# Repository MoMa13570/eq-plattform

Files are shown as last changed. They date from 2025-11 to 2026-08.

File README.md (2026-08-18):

# EQ Plattform

Eine DIY-Nachführplattform für Dobson-Teleskope mit Arduino Uno, Nano oder
ESP32, NEMA17-Schrittmotor und TMC2209-Treiber. Die ESP32-Firmware bringt
zusätzlich einen eigenen WLAN-Hotspot und eine responsive Websteuerung mit.

## Direkt starten

- [Projekt-Website und Bauübersicht](https://moma13570.github.io/eq-plattform/)
- [Firmware im Browser installieren](https://moma13570.github.io/eq-plattform/flasher/)
- [Aktuelle Firmware herunterladen](https://github.com/MoMa13570/eq-plattform/releases/latest)
- [Fertige Firmware im Repository](release/)
- [Bauanleitung als PDF](build_instructions/buildinstruction_EQ_Plattform.pdf)
- [Stückliste als CSV](part%20list/Teileliste_DM%20EQ%20Plattform.csv)

Der Browser-Flasher benötigt Chrome oder Edge auf einem Desktop-Rechner. Die
HEX-Datei wird lokal verarbeitet und nicht an einen Server übertragen.

## Inhalt

- `hardware/mechanical/` – STEP-Dateien für Standard- und Simple-Mechanik
- `hardware/circuitboard/` – Schaltplan, PCB-Daten und Elektronikgehäuse
- `software/EQ-Plattform_TMC2209/` – PlatformIO-Projekt und Firmware-Quellcode
- `part list/` – Stückliste
- `build_instructions/` – ausführliche Bauanleitung
- `flasher/` – statischer Web-Serial-Flasher

## Firmware selbst kompilieren

Das PlatformIO-Projekt unterstützt Arduino Uno, Nano und ESP32:

```text
software/EQ-Plattform_TMC2209/
```

Die wichtigsten Umgebungen in `platformio.ini` sind `uno`, `nano` und `esp32`.
Details zur ESP32-Pinbelegung und Web-App stehen in der
[Software-Dokumentation](software/README.md). Für Uno/Nano ist der fertige
HEX-Download im aktuellen GitHub Release einfacher.

## Lizenz

Siehe [LICENSE.rtf](LICENSE.rtf).

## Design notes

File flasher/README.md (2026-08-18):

# EQ Firmware Flasher

Statische Chrome-Web-App zum Übertragen einer Intel-HEX-Firmware auf:

- Arduino Uno
- Arduino Nano
- Arduino Nano (alter Bootloader)
- ESP32 DevKit V1

Die App verwendet die Web Serial API direkt im Browser. Es gibt kein Backend,
kein Benutzerkonto und keinen Upload der Firmware an einen Server.

Für Uno/Nano verarbeitet der Flasher Intel-HEX und spricht das STK500v1-
Bootloaderprotokoll. Für den ESP32 wird ein zusammengeführtes Factory-BIN ab
Adresse `0x0` mit Espressifs `esptool-js` übertragen. Die passenden fertigen
Dateien liegen im Verzeichnis [`release/`](../release/).

`esptool-js` 0.5.7 ist lokal unter `vendor/` eingebunden, sodass der Flasher
zur Laufzeit keine Bibliothek von einem externen CDN nachladen muss. Die
Apache-2.0-Lizenz liegt daneben.

Nach der Veröffentlichung über GitHub Pages:

<https://moma13570.github.io/eq-plattform/flasher/>

Voraussetzungen: Chrome oder Edge auf einem Desktop-Rechner sowie eine
HTTPS-Verbindung (bei GitHub Pages automatisch gegeben).

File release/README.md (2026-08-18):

# Fertige Firmware

- `EQ-Plattform-UNO-NANO.hex` – Arduino Uno oder Nano mit ATmega328P
- `EQ-Plattform-ESP32.factory.bin` – vollständiges ESP32 DevKit V1 Image

Beide Dateien können direkt im [Web-Flasher](../flasher/index.html) verwendet
werden. Das ESP32-Factory-Image enthält Bootloader, Partitionstabelle und
Anwendung und wird ab Flash-Adresse `0x0` installiert.

Bei einem Git-Tag wie `v1.0.0` baut der Workflow `firmware-release.yml` beide
Dateien erneut und hängt sie zusammen mit `SHA256SUMS.txt` an den GitHub
Release. Er kann außerdem manuell als Workflow gestartet werden.

## SHA-256

```text
a018c9d37cf94f3ed3204fbee39d7b598d2756b0838089d841da10bda20a1d82  EQ-Plattform-UNO-NANO.hex
f4a5176cb3ebf21efc48b64490342c9812eb65955f2bdc9ecd68fb28551eea28  EQ-Plattform-ESP32.factory.bin
```

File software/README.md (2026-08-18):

# Firmware

## Einfach installieren

1. Die aktuelle HEX-Datei im
   [GitHub Release](https://github.com/MoMa13570/eq-plattform/releases/latest)
   herunterladen.
2. Den
   [EQ Firmware Flasher](https://moma13570.github.io/eq-plattform/flasher/)
   in Chrome oder Edge öffnen.
3. Board und HEX-Datei auswählen, Arduino verbinden und installieren.

Für den ESP32 im Flasher `ESP32 DevKit` wählen und die mitgelieferte
`EQ-Plattform-ESP32.factory.bin` verwenden. Der Flasher kann sie direkt laden;
ein vorheriger Download ist nicht nötig.

Die veröffentlichte Firmware ist für ATmega328P-Boards ausgelegt. Dasselbe
Firmware-Abbild funktioniert auf Arduino Uno und Nano; im Flasher wird das
Board ausgewählt, damit das passende Bootloader-Protokoll verwendet wird.

## ESP32 mit Web-App

Zusätzlich gibt es die PlatformIO-Umgebung `esp32` für ein ESP32 DevKit V1.
Sie enthält dieselbe Steuerung einschließlich OLED, Endschaltern, Tracking,
Mondrate und Homing. Der ESP32 öffnet außerdem den Hotspot `EQ-Plattform`
(Passwort `eqplattform`). Nach dem Verbinden ist die Steuerung unter
`http://192.168.4.1` erreichbar. Auf vielen Smartphones öffnet sich die
Web-App durch die integrierte Captive-Portal-Erkennung automatisch.

Die Web-App zeigt den Live-Status und bietet:

- Tracking starten/stoppen, Richtung Nord/Süd und Mondrate
- Homing und Sofort-Stopp
- konfigurierbaren Poti-Bereich oder Betrieb ohne Poti
- getrennte TMC2209-Ströme für Tracking, schnelles und langsames Homing
- einstellbare Homing-Geschwindigkeiten

Alle Einstellungen werden im Flash des ESP32 gespeichert.

### Pinbelegung ESP32 DevKit V1

| Funktion | GPIO |
| --- | ---: |
| STEP / DIR / EN | 25 / 26 / 27 |
| Poti | 34 |
| Richtung Nord / Süd | 32 / 33 |
| Home-Taster | 13 |
| Endschalter Home / Ende | 18 / 19 |
| TMC2209 UART RX / TX | 16 / 17 |
| OLED SDA / SCL | 21 / 22 |

Taster, Richtungsschalter und Endschalter schalten gegen GND. Der ESP32 ist
nicht 5-V-tolerant; alle Signale müssen mit 3,3 V kompatibel sein. Die Masse
von ESP32, TMC2209 und Motorversorgung muss verbunden werden.

Beim üblichen BTT TMC2209 V1.3 werden GPIO 16 (RX) direkt und GPIO 17 (TX)
über einen 1-kΩ-Widerstand gemeinsam an `PDN_UART` angeschlossen. Die
eingestellten RMS-Ströme sind Sicherheitsgrenzen der Software, ersetzen aber
nicht die Prüfung, ob Motor, Treiber und Kühlung dafür ausgelegt sind.

Kompilieren und hochladen:

```bash
cd software/EQ-Plattform_TMC2209
pio run -e esp32
pio run -e esp32 -t upload
```

Fertige Images für den Web-Flasher liegen unter [`release/`](../release/).
Für den ESP32 muss dort die Datei mit der Endung `.factory.bin` verwendet
werden; die normale PlatformIO-Datei `firmware.bin` enthält nur die Anwendung.

## Quellcode

Das PlatformIO-Projekt befindet sich in
[`EQ-Plattform_TMC2209/`](EQ-Plattform_TMC2209/). Die Umgebungen `uno`, `nano`
und `esp32` bauen die jeweilige Firmware mit Endstop- und Homing-Unterstützung.

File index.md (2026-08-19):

---
title: EQ Plattform
description: DIY-Nachführplattform für Dobson-Teleskope mit Arduino, NEMA17 und TMC2209
lang: de
---

<style>
  :root {
    --eq-bg: #f2f6f5;
    --eq-surface: #ffffff;
    --eq-surface-soft: #e9f0ef;
    --eq-ink: #13272b;
    --eq-muted: #5d7074;
    --eq-line: #d4e0de;
    --eq-accent: #087e84;
    --eq-accent-dark: #075a60;
    --eq-warm: #e99b38;
    --eq-red: #c8322b;
    --eq-night: #0b2d32;
    --eq-radius: 1.25rem;
    --eq-shadow: 0 24px 60px rgba(11, 45, 50, 0.1);
  }

  html {
    scroll-behavior: smooth;
  }

  body {
    margin: 0;
    background: var(--eq-bg);
  }

  .container-lg {
    max-width: none !important;
    margin: 0 !important;
    padding: 0 !important;
  }

  .container-lg > h1:first-child {
    display: none;
  }

  .markdown-body {
    color: var(--eq-ink);
    font-family: Inter, ui-sans-serif, -apple-system, BlinkMacSystemFont, "Segoe UI", sans-serif;
    font-size: 16px;
    line-height: 1.65;
  }

  .markdown-body h1,
  .markdown-body h2,
  .markdown-body h3,
  .markdown-body p,
  .markdown-body figure,
  .markdown-body ul {
    margin-top: 0;
  }

  .markdown-body a {
    color: var(--eq-accent-dark);
  }

  .eq-page {
    min-height: 100vh;
    overflow: hidden;
  }

  .eq-wrap {
    width: min(1120px, calc(100% - 40px));
    margin: 0 auto;
  }

  .eq-nav {
    position: relative;
    z-index: 10;
    display: flex;
    min-height: 76px;
    align-items: center;
    justify-content: space-between;
    gap: 2rem;
  }

  .eq-brand {
    display: inline-flex;
    align-items: center;
    gap: 0.75rem;
    color: var(--eq-ink) !important;
    font-weight: 800;
    letter-spacing: -0.025em;
    text-decoration: none !important;
  }

  .eq-brand-mark {
    display: grid;
    width: 2.25rem;
    height: 2.25rem;
    place-items: center;
    border-radius: 0.7rem;
    background: var(--eq-night);
    color: #ffffff;
    font-size: 0.78rem;
    letter-spacing: -0.04em;
  }

  .eq-nav-links {
    display: flex;
    align-items: center;
    gap: 1.3rem;
  }

  .eq-nav-links a {
    color: var(--eq-muted) !important;
    font-size: 0.9rem;
    font-weight: 650;
    text-decoration: none !important;
  }

  .eq-nav-links a:hover {
    color: var(--eq-accent-dark) !important;
  }

  .eq-hero {
    display: grid;
    grid-template-columns: minmax(0, 1fr) minmax(360px, 0.86fr);
    gap: clamp(2rem, 5vw, 5rem);
    align-items: center;
    padding: clamp(3rem, 7vw, 6rem) 0 clamp(4rem, 8vw, 7rem);
  }

  .eq-kicker {
    margin-bottom: 1rem !important;
    color: var(--eq-accent-dark);
    font: 750 0.78rem ui-monospace, SFMono-Regular, Menlo, monospace;
    letter-spacing: 0.13em;
    text-transform: uppercase;
  }

  .eq-hero h1 {
    max-width: 12ch;
    margin-bottom: 1.4rem;
    color: var(--eq-night);
    font-size: clamp(3.3rem, 8vw, 6.5rem);
    font-weight: 720;
    letter-spacing: -0.072em;
    line-height: 0.9;
  }

  .eq-lead {
    max-width: 42rem;
    margin-bottom: 1.6rem !important;
    color: var(--eq-muted);
    font-size: clamp(1.05rem, 2vw, 1.25rem);
    line-height: 1.6;
  }

  .eq-actions {
    display: flex;
    flex-wrap: wrap;
    gap: 0.75rem;
  }

  .eq-button {
    display: inline-flex;
    min-height: 3rem;
    align-items: center;
    justify-content: center;
    padding: 0.7rem 1.1rem;
    border: 1px solid var(--eq-accent);
    border-radius: 0.75rem;
    background: var(--eq-accent);
    color: #ffffff !important;
    font-size: 0.94rem;
    font-weight: 750;
    text-decoration: none !important;
    transition: transform 160ms ease, box-shadow 160ms ease;
  }

  .eq-button:hover {
    transform: translateY(-2px);
    box-shadow: 0 12px 24px rgba(8, 126, 132, 0.18);
  }

  .eq-button.secondary {
    border-color: var(--eq-line);
    background: var(--eq-surface);
    color: var(--eq-ink) !important;
  }

  .eq-facts {
    display: flex;
    flex-wrap: wrap;
    gap: 0.55rem;
    margin-top: 1.6rem;
  }

  .eq-fact {
    padding: 0.35rem 0.65rem;
    border: 1px solid var(--eq-line);
    border-radius: 999px;
    background: rgba(255, 255, 255, 0.55);
    color: var(--eq-muted);
    font-size: 0.78rem;
    font-weight: 650;
  }

  .eq-hero-media {
    position: relative;
    margin: 0;
  }

  .eq-hero-media::before {
    position: absolute;
    inset: -10% -12% auto auto;
    width: 75%;
    aspect-ratio: 1;
    border-radius: 50%;
    background: rgba(8, 126, 132, 0.12);
    content: "";
    filter: blur(1px);
  }

  .eq-hero-media img {
    position: relative;
    width: 100%;
    aspect-ratio: 1.05;
    border: 1px solid rgba(255, 255, 255, 0.8);
    border-radius: 2rem;
    object-fit: cover;
    box-shadow: var(--eq-shadow);
  }

  .eq-hero-media figcaption {
    position: absolute;
    right: 1rem;
    bottom: 1rem;
    max-width: 14rem;
    padding: 0.55rem 0.75rem;
    border: 1px solid rgba(255, 255, 255, 0.35);
    border-radius: 0.65rem;
    background: rgba(11, 45, 50, 0.84);
    color: #ffffff;
    font-size: 0.75rem;
    backdrop-filter: blur(8px);
  }

  .eq-intro {
    display: grid;
    grid-template-columns: minmax(220px, 0.3fr) minmax(0, 0.7fr);
    gap: clamp(1.5rem, 5vw, 4rem);
    align-items: start;
    margin-bottom: 0;
    padding: clamp(1.5rem, 4vw, 2.5rem);
    border: 1px solid var(--eq-line);
    border-radius: var(--eq-radius);
    background: var(--eq-surface);
    box-shadow: 0 18px 45px rgba(11, 45, 50, 0.07);
  }

  .eq-intro h2 {
    margin-bottom: 0;
    color: var(--eq-night);
    font-size: clamp(1.8rem, 4vw, 2.7rem);
    font-weight: 720;
    letter-spacing: -0.05em;
    line-height: 1;
  }

  .eq-intro p {
    margin-bottom: 0;
    color: var(--eq-muted);
    font-size: 1.04rem;
    line-height: 1.75;
  }

  .eq-video {
    display: grid;
    grid-template-columns: minmax(240px, 0.38fr) minmax(0, 0.62fr);
    gap: clamp(2rem, 6vw, 5rem);
    align-items: center;
  }

  .eq-video-copy h2 {
    margin-bottom: 1.1rem;
    color: var(--eq-night);
    font-size: clamp(2.1rem, 5vw, 3.8rem);
    font-weight: 720;
    letter-spacing: -0.055em;
    line-height: 1;
  }

  .eq-video-copy > p:last-child {
    margin-bottom: 0;
    color: var(--eq-muted);
    font-size: 1.05rem;
  }

  .eq-video-placeholder {
    position: relative;
    display: grid;
    aspect-ratio: 16 / 9;
    overflow: hidden;
    place-items: center;
    border: 1px solid rgba(255, 255, 255, 0.14);
    border-radius: var(--eq-radius);
    background:
      radial-gradient(circle at 50% 35%, rgba(8, 126, 132, 0.42), transparent 46%),
      var(--eq-night);
    box-shadow: var(--eq-shadow);
    color: #ffffff;
  }

  .eq-video-placeholder::before {
    position: absolute;
    inset: 1rem;
    border: 1px solid rgba(255, 255, 255, 0.08);
    border-radius: calc(var(--eq-radius) - 0.4rem);
    content: "";
  }

  .eq-video-placeholder-content {
    position: relative;
    z-index: 1;
    display: grid;
    justify-items: center;
    padding: 2rem;
    text-align: center;
  }

  .eq-video-play-icon {
    position: relative;
    width: 4rem;
    height: 4rem;
    margin-bottom: 1rem;
    border: 1px solid rgba(255, 255, 255, 0.3);
    border-radius: 50%;
    background: rgba(255, 255, 255, 0.12);
    backdrop-filter: blur(8px);
  }

  .eq-video-play-icon::after {
    position: absolute;
    top: 50%;
    left: 53%;
    border-top: 0.55rem solid transparent;
    border-bottom: 0.55rem solid transparent;
    border-left: 0.85rem solid #ffffff;
    content: "";
    transform: translate(-50%, -50%);
  }

  .eq-video-placeholder strong {
    color: #ffffff;
    font-size: 1.1rem;
  }

  .eq-video-placeholder small {
    margin-top: 0.25rem;
    color: #b7c8c8;
  }

  .eq-section {
    padding: clamp(4rem, 8vw, 7rem) 0;
  }

  .eq-section.soft {
    position: relative;
  }

  .eq-section.soft::before {
    position: absolute;
    z-index: -1;
    top: 0;
    right: 50%;
    bottom: 0;
    left: 50%;
    width: 100vw;
    margin-right: -50vw;
    margin-left: -50vw;
    background: var(--eq-surface-soft);
    content: "";
  }

  .eq-section.dark {
    position: relative;
    color: #ffffff;
  }

  .eq-section.dark::before {
    position: absolute;
    z-index: -1;
    top: 0;
    right: 50%;
    bottom: 0;
    left: 50%;
    width: 100vw;
    margin-right: -50vw;
    margin-left: -50vw;
    background: var(--eq-night);
    content: "";
  }

  .eq-section-heading {
    display: grid;
    grid-template-columns: minmax(0, 0.62fr) minmax(280px, 0.38fr);
    gap: 3rem;
    align-items: end;
    margin-bottom: 2.2rem;
  }

  .eq-section-heading h2,
  .eq-split-copy h2 {
    margin-bottom: 0;
    color: inherit;
    font-size: clamp(2.1rem, 5vw, 3.8rem);
    font-weight: 720;
    letter-spacing: -0.055em;
    line-height: 1;
  }

  .eq-section-heading p {
    margin-bottom: 0;
    color: var(--eq-muted);
  }

  .eq-section.dark .eq-section-heading p,
  .eq-section.dark .eq-muted {
    color: #b7c8c8;
  }

  .eq-split {
    display: grid;
    grid-template-columns: minmax(0, 0.9fr) minmax(360px, 1.1fr);
    gap: clamp(2rem, 6vw, 5rem);
    align-items: center;
  }

  .eq-split.reverse {
    grid-template-columns: minmax(360px, 1.1fr) minmax(0, 0.9fr);
  }

  .eq-split-copy > p {
    color: var(--eq-muted);
    font-size: 1.05rem;
  }

  .eq-split-copy h2 {
    margin-bottom: 1.2rem;
  }

  .eq-diagram,
  .eq-photo-card {
    margin: 0;
    overflow: hidden;
    border: 1px solid var(--eq-line);
    border-radius: var(--eq-radius);
    background: var(--eq-surface);
    box-shadow: var(--eq-shadow);
  }

  .eq-diagram {
    padding: 1.25rem;
  }

  .eq-diagram img,
  .eq-photo-card img {
    display: block;
    width: 100%;
    margin: 0;
  }

  .eq-diagram figcaption,
  .eq-photo-card figcaption {
    padding: 0.8rem 1rem 0.95rem;
    color: var(--eq-muted);
    font-size: 0.8rem;
  }

  .eq-checks {
    display: grid;
    gap: 0.8rem;
    margin: 1.5rem 0 0;
    padding: 0;
    list-style: none;
  }

  .eq-checks li {
    position: relative;
    padding-left: 1.7rem;
    color: var(--eq-ink);
  }

  .eq-checks li::before {
    position: absolute;
    top: 0.42rem;
    left: 0;
    width: 0.7rem;
    height: 0.7rem;
    border: 2px solid var(--eq-accent);
    border-radius: 50%;
    content: "";
  }

  .eq-card-grid {
    display: grid;
    grid-template-columns: repeat(3, minmax(0, 1fr));
    gap: 1rem;
  }

  .eq-card {
    padding: 1.35rem;
    border: 1px solid var(--eq-line);
    border-radius: 1rem;
    background: var(--eq-surface);
  }

  .eq-card-label {
    display: inline-block;
    margin-bottom: 1rem;
    color: var(--eq-accent-dark);
    font: 700 0.72rem ui-monospace, SFMono-Regular, Menlo, monospace;
    letter-spacing: 0.1em;
    text-transform: uppercase;
  }

  .eq-card h3 {
    margin-bottom: 0.55rem;
    color: var(--eq-ink);
    font-size: 1.15rem;
  }

  .eq-card p,
  .eq-card li {
    color: var(--eq-muted);
    font-size: 0.93rem;
  }

  .eq-card ul {
    margin-bottom: 0;
    padding-left: 1.1rem;
  }

  .eq-step-grid {
    display: grid;
    grid-template-columns: repeat(3, minmax(0, 1fr));
    gap: 1rem;
  }

  .eq-step {
    min-height: 12rem;
    padding: 1.3rem;
    border: 1px solid var(--eq-line);
    border-radius: 1rem;
    background: rgba(255, 255, 255, 0.72);
  }

  .eq-step-number {
    display: grid;
    width: 2.15rem;
    height: 2.15rem;
    margin-bottom: 1.8rem;
    place-items: center;
    border-radius: 0.65rem;
    background: var(--eq-night);
    color: #ffffff;
    font: 700 0.78rem ui-monospace, SFMono-Regular, Menlo, monospace;
  }

  .eq-step h3 {
    margin-bottom: 0.45rem;
    color: var(--eq-ink);
    font-size: 1.05rem;
  }

  .eq-step p {
    margin-bottom: 0;
    color: var(--eq-muted);
    font-size: 0.9rem;
  }

  .eq-gallery {
    display: grid;
    grid-template-columns: repeat(3, minmax(0, 1fr));
    gap: 1rem;
    margin-top: 1rem;
  }

  .eq-photo-card img {
    aspect-ratio: 1.25;
    object-fit: cover;
  }

  .eq-dark-grid {
    display: grid;
    grid-template-columns: 0.9fr 1.1fr;
    gap: 1rem;
  }

  .eq-dark-card {
    overflow: hidden;
    border: 1px solid rgba(255, 255, 255, 0.13);
    border-radius: var(--eq-radius);
    background: rgba(255, 255, 255, 0.06);
  }

  .eq-dark-card img {
    display: block;
    width: 100%;
    aspect-ratio: 1.25;
    object-fit: cover;
  }

  .eq-dark-card-copy {
    padding: 1.25rem;
  }

  .eq-dark-card h3 {
    margin-bottom: 0.5rem;
    color: #ffffff;
  }

  .eq-dark-card p {
    margin-bottom: 0;
    color: #b7c8c8;
    font-size: 0.93rem;
  }

  .eq-note {
    margin-top: 1rem;
    padding: 1rem 1.1rem;
    border-left: 0.3rem solid var(--eq-warm);
    border-radius: 0.25rem 0.75rem 0.75rem 0.25rem;
    background: #fff6e9;
    color: #614619;
    font-size: 0.92rem;
  }

  .eq-projection {
    padding: clamp(1.4rem, 4vw, 2.4rem);
    border: 1px solid var(--eq-line);
    border-radius: var(--eq-radius);
    background: var(--eq-surface);
    box-shadow: var(--eq-shadow);
  }

  .eq-projection-top,
  .eq-projection-control-head {
    display: flex;
    align-items: center;
    justify-content: space-between;
    gap: 1rem;
  }

  .eq-projection-top {
    margin-bottom: 1.5rem;
  }

  .eq-projection-top p {
    max-width: 44rem;
    margin-bottom: 0;
    color: var(--eq-muted);
  }

  .eq-projection-play {
    flex: 0 0 auto;
    cursor: pointer;
  }

  .eq-projection-play:disabled {
    cursor: wait;
    opacity: 0.65;
  }

  .eq-projection-3d-shell {
    position: relative;
    overflow: hidden;
    border: 1px solid var(--eq-line);
    border-radius: 1rem;
    background:
      radial-gradient(circle at 50% 42%, rgba(8, 126, 132, 0.09), transparent 52%),
      var(--eq-bg);
  }

  .eq-projection-3d {
    width: 100%;
    height: clamp(25rem, 52vw, 35rem);
    cursor: grab;
    touch-action: none;
  }

  .eq-projection-3d:active {
    cursor: grabbing;
  }

  .eq-projection-3d canvas {
    display: block;
    width: 100%;
    height: 100%;
  }

  .eq-projection-3d-loading {
    display: grid;
    height: 100%;
    place-items: center;
    color: var(--eq-muted);
    font-size: 0.88rem;
  }

  .eq-projection-3d-status {
    position: absolute;
    top: 0.8rem;
    left: 0.8rem;
    display: flex;
    flex-wrap: wrap;
    gap: 0.45rem;
    pointer-events: none;
  }

  .eq-projection-3d-value {
    padding: 0.35rem 0.55rem;
    border: 1px solid var(--eq-line);
    border-radius: 0.55rem;
    background: rgba(255, 255, 255, 0.86);
    color: var(--eq-ink);
    font-size: 0.78rem;
    font-weight: 650;
    font-variant-numeric: tabular-nums;
    backdrop-filter: blur(8px);
  }

  .eq-projection-viewbar {
    display: flex;
    align-items: center;
    justify-content: space-between;
    gap: 1rem;
    margin-top: 0.8rem;
  }

  .eq-projection-view-buttons,
  .eq-projection-legend {
    display: flex;
    flex-wrap: wrap;
    align-items: center;
    gap: 0.55rem;
  }

  .eq-projection-view-button {
    min-height: 2.35rem;
    padding: 0.42rem 0.72rem;
    border: 1px solid var(--eq-line);
    border-radius: 0.6rem;
    background: var(--eq-surface);
    color: var(--eq-ink);
    cursor: pointer;
    font: inherit;
    font-size: 0.82rem;
    font-weight: 650;
  }

  .eq-projection-view-button[aria-pressed="true"] {
    border-color: var(--eq-accent);
    background: var(--eq-surface-soft);
    color: var(--eq-accent-dark);
  }

  .eq-projection-hint {
    color: var(--eq-muted);
    font-size: 0.8rem;
  }

  .eq-projection-legend {
    margin-top: 0.9rem;
    color: var(--eq-muted);
    font-size: 0.78rem;
  }

  .eq-projection-legend span {
    display: inline-flex;
    align-items: center;
    gap: 0.35rem;
  }

  .eq-projection-swatch {
    width: 0.8rem;
    height: 0.8rem;
    border-radius: 0.25rem;
    background: var(--swatch);
  }

  .eq-projection-controls {
    display: grid;
    grid-template-columns: repeat(2, minmax(0, 1fr));
    gap: 1rem 2rem;
    margin-top: 1rem;
    padding-top: 1.25rem;
    border-top: 1px solid var(--eq-line);
  }

  .eq-projection-control label {
    color: var(--eq-ink);
    font-size: 0.88rem;
    font-weight: 650;
  }

  .eq-projection-control output {
    color: var(--eq-muted);
    font-size: 0.84rem;
    font-variant-numeric: tabular-nums;
  }

  .eq-projection-control input {
    width: 100%;
    margin: 0.65rem 0 0;
    accent-color: var(--eq-accent);
  }

  .eq-projection-progress {
    height: 3px;
    margin-top: 1rem;
    overflow: hidden;
    border-radius: 999px;
    background: var(--eq-surface-soft);
  }

  .eq-projection-progress span {
    display: block;
    width: 0;
    height: 100%;
    background: var(--eq-accent);
  }

  .eq-resource-grid {
    display: grid;
    grid-template-columns: repeat(3, minmax(0, 1fr));
    gap: 1rem;
  }

  .eq-resource {
    display: flex;
    min-height: 11.5rem;
    flex-direction: column;
    justify-content: space-between;
    padding: 1.35rem;
    border: 1px solid var(--eq-line);
    border-radius: 1rem;
    background: var(--eq-surface);
    color: var(--eq-ink) !important;
    text-decoration: none !important;
    transition: transform 160ms ease, border-color 160ms ease;
  }

  .eq-resource:hover {
    transform: translateY(-3px);
    border-color: var(--eq-accent);
  }

  .eq-resource-type {
    color: var(--eq-accent-dark);
    font: 700 0.72rem ui-monospace, SFMono-Regular, Menlo, monospace;
    letter-spacing: 0.1em;
    text-transform: uppercase;
  }

  .eq-resource strong {
    display: block;
    margin: 1.4rem 0 0.35rem;
    color: var(--eq-ink);
    font-size: 1.05rem;
  }

  .eq-resource small {
    color: var(--eq-muted);
    line-height: 1.5;
  }

  .eq-resource-arrow {
    align-self: flex-end;
    color: var(--eq-accent);
    font-size: 1.2rem;
  }

  .eq-final {
    display: grid;
    grid-template-columns: minmax(0, 1fr) auto;
    gap: 2rem;
    align-items: center;
    margin: clamp(4rem, 8vw, 7rem) 0;
    padding: clamp(1.7rem, 4vw, 3rem);
    border-radius: var(--eq-radius);
    background: var(--eq-night);
    color: #ffffff;
  }

  .eq-final h2 {
    margin-bottom: 0.55rem;
    color: #ffffff;
    font-size: clamp(1.8rem, 4vw, 2.8rem);
    letter-spacing: -0.045em;
  }

  .eq-final p {
    max-width: 44rem;
    margin-bottom: 0;
    color: #b7c8c8;
  }

  .eq-footer {
    display: flex;
    padding: 1.5rem 0 2.5rem;
    border-top: 1px solid var(--eq-line);
    justify-content: space-between;
    gap: 1rem;
    color: var(--eq-muted);
    font-size: 0.82rem;
  }

  @media (max-width: 880px) {
    .eq-hero,
    .eq-split,
    .eq-split.reverse,
    .eq-intro,
    .eq-video,
    .eq-section-heading,
    .eq-dark-grid {
      grid-template-columns: 1fr;
    }

    .eq-hero {
      padding-top: 2.5rem;
    }

    .eq-hero-copy {
      order: 1;
    }

    .eq-hero-media {
      order: 2;
    }

    .eq-card-grid,
    .eq-step-grid,
    .eq-resource-grid {
      grid-template-columns: repeat(2, minmax(0, 1fr));
    }

    .eq-section-heading {
      gap: 1rem;
    }

  }

  @media (max-width: 620px) {
    .eq-wrap {
      width: min(100% - 24px, 1120px);
    }

    .eq-nav {
      min-height: 66px;
    }

    .eq-nav-links {
      display: none;
    }

    .eq-hero {
      gap: 2.4rem;
      padding-bottom: 4rem;
    }

    .eq-hero h1 {
      font-size: clamp(3.2rem, 17vw, 4.8rem);
    }

    .eq-hero-media img {
      border-radius: 1.25rem;
    }

    .eq-actions {
      align-items: stretch;
      flex-direction: column;
    }

    .eq-button {
      width: 100%;
    }

    .eq-card-grid,
    .eq-step-grid,
    .eq-gallery,
    .eq-resource-grid {
      grid-template-columns: 1fr;
    }

    .eq-final {
      grid-template-columns: 1fr;
    }

    .eq-footer {
      flex-direction: column;
    }

    .eq-projection-top {
      align-items: flex-start;
      flex-direction: column;
      gap: 0.35rem;
    }

    .eq-projection-play {
      width: 100%;
    }

    .eq-projection-controls {
      grid-template-columns: 1fr;
    }

    .eq-projection-3d {
      height: 24rem;
    }

    .eq-projection-viewbar {
      align-items: flex-start;
      flex-direction: column;
    }

    .eq-projection-view-buttons {
      width: 100%;
    }

    .eq-projection-view-button {
      flex: 1 1 auto;
    }
  }

  @media (prefers-reduced-motion: reduce) {
    html {
      scroll-behavior: auto;
    }

    *,
    *::before,
    *::after {
      transition-duration: 0.01ms !important;
    }
  }
</style>

<div class="eq-page">
  <div class="eq-wrap">
    <nav class="eq-nav" aria-label="Hauptnavigation">
      <a class="eq-brand" href="./">
        <span class="eq-brand-mark">EQ</span>
        <span>EQ Plattform</span>
      </a>
      <div class="eq-nav-links">
        <a href="#video">Video</a>
        <a href="#prinzip">Prinzip</a>
        <a href="#projektion">Projektion</a>
        <a href="#aufbau">Aufbau</a>
        <a href="#antrieb">Antrieb</a>
        <a href="#downloads">Downloads</a>
      </div>
    </nav>

    <main>
      <header class="eq-hero">
        <div class="eq-hero-copy">
          <p class="eq-kicker">DIY-Nachführung für Dobson-Teleskope</p>
          <h1>Mehr Zeit am Objekt.</h1>
          <p class="eq-lead">
            Eine kompakte äquatoriale Plattform, die die Erdrotation ausgleicht und
            Himmelsobjekte länger im Gesichtsfeld hält. Mechanik, Elektronik und
            Firmware sind vollständig dokumentiert.
          </p>
          <div class="eq-actions">
            <a class="eq-button secondary" href="build_instructions/buildinstruction_EQ_Plattform.pdf">Bauanleitung öffnen</a>
            <a class="eq-button secondary" href="#downloads">Dateien herunterladen</a>
            <a class="eq-button" href="flasher/">Firmware installieren</a>
          </div>
        </div>
        <figure class="eq-hero-media">
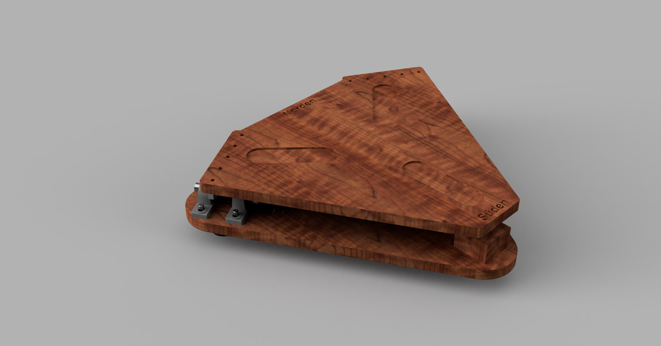
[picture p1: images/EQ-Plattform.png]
Fertig aufgebaute EQ Plattform
          
          <figcaption>Fertige EQ Plattform mit motorisierter Nachführung</figcaption>
        </figure>
      </header>

      <section class="eq-intro" aria-labelledby="worum-es-geht">
        <h2 id="worum-es-geht">Worum es geht</h2>
        <p>
          Das Projekt verfolgt die Idee einer Do-it-yourself-EQ-Plattform, die sich
          vergleichsweise preisgünstig herstellen lässt, ohne dass man zwangsläufig
          handwerkliche Fähigkeiten benötigt. Es ähnelt eher einem Bausatz eines gewissen Möbelhauses –
          daher nennen wir es spaßeshalber Stjärnföljare: Die Teile werden online
          bestellt, und der Benutzer baut die Plattform nach Anleitung zusammen.
          Die Kosten fallen dabei deutlich niedriger aus als bei kommerziell
          erhältlichen Plattformen. Im Folgenden werden die nötigen Teilelisten und
          Bauschritte im Einzelnen erklärt.
        </p>
      </section>

      <section class="eq-section eq-video" id="video" aria-labelledby="video-title">
        <div class="eq-video-copy">
          <p class="eq-kicker">Projektvideo</p>
          <h2 id="video-title">Die EQ Plattform in Aktion</h2>
          <p>
            Ein ausführliches YouTube-Video mit Projektüberblick, Aufbau und
            Praxiseinsatz ist in Vorbereitung. Sobald es veröffentlicht ist,
            kannst du es direkt hier ansehen.
          </p>
        </div>
        <div
          class="eq-video-placeholder"
          role="img"
          aria-label="Platzhalter für das kommende YouTube-Video zur EQ Plattform"
        >
          <div class="eq-video-placeholder-content">
            <span class="eq-video-play-icon" aria-hidden="true"></span>
            <strong>Video erscheint in Kürze</strong>
            <small>Projektüberblick · Aufbau · Praxiseinsatz</small>
          </div>
        </div>
      </section>

      <section class="eq-section soft" id="aufbau">
        <div class="eq-section-heading">
          <h2>Mechanik in sechs Schritten</h2>
          <p>
            Die Website zeigt den Ablauf. Maße, Bohrbilder und Detailfotos stehen
            in der PDF-Bauanleitung.
          </p>
        </div>
        <div class="eq-step-grid">
          <article class="eq-step">
            <span class="eq-step-number">01</span>
            <h3>Möbelfüße montieren</h3>
            <p>Füße in den vorgesehenen Ausfräsungen der Grundplatte verschrauben.</p>
          </article>
          <article class="eq-step">
            <span class="eq-step-number">02</span>
            <h3>Stehlager vormontieren</h3>
            <p>Vier UCP204-Lager zunächst nur handfest auf der Grundplatte befestigen.</p>
          </article>
          <article class="eq-step">
            <span class="eq-step-number">03</span>
            <h3>Linearwellen einsetzen</h3>
            <p>Wellen ausrichten, in die Lager schieben und mit Madenschrauben fixieren.</p>
          </article>
          <article class="eq-step">
            <span class="eq-step-number">04</span>
            <h3>Tischplatte vorbereiten</h3>
            <p>M10-Gewindeeinsatz setzen und das Kugelgelenk einschrauben.</p>
          </article>
          <article class="eq-step">
            <span class="eq-step-number">05</span>
            <h3>Kreissegmente montieren</h3>
            <p>M5-Gewindeeinsätze setzen und beide Segmente an der Tischplatte verschrauben.</p>
          </article>
          <article class="eq-step">
            <span class="eq-step-number">06</span>
            <h3>Südlager befestigen</h3>
            <p>Holzblock mit M8-Gewindeeinsätzen montieren und die Leichtgängigkeit prüfen.</p>
          </article>
        </div>
        <div class="eq-gallery">
          <figure class="eq-photo-card">
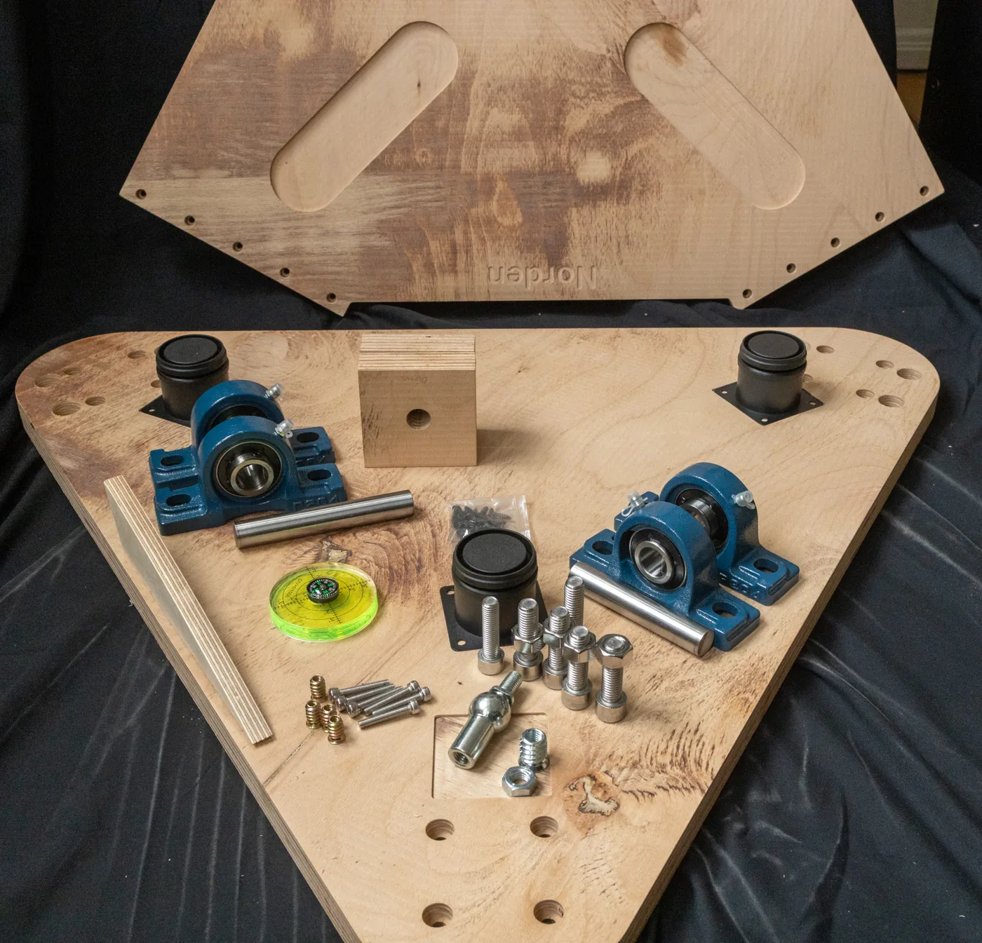
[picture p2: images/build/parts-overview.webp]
Holzplatten, Lager, Wellen und weitere mechanische Bauteile
            
            <figcaption>Mechanische Bauteile vor dem Zusammenbau</figcaption>
          </figure>
          <figure class="eq-photo-card">
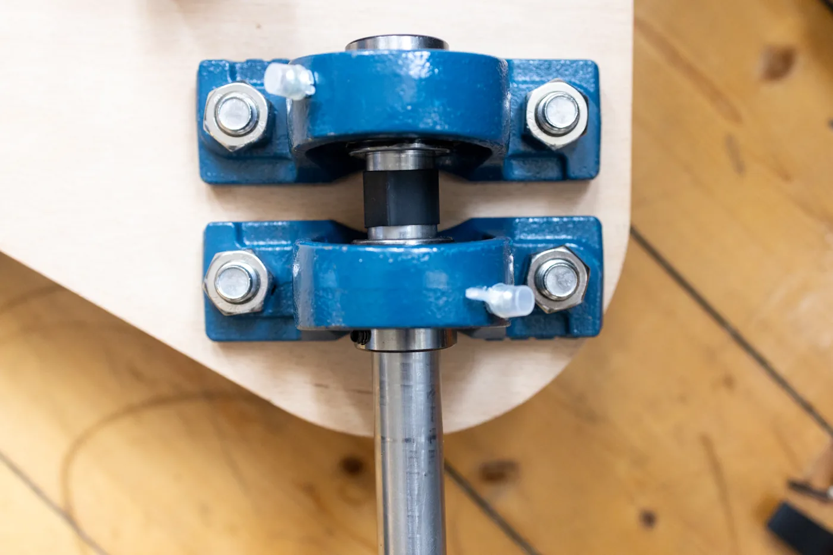
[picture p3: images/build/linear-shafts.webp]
In vier Stehlagern montierte Linearwellen
            
            <figcaption>Nordlager mit UCP204-Stehlagern und Linearwellen</figcaption>
          </figure>
          <figure class="eq-photo-card">
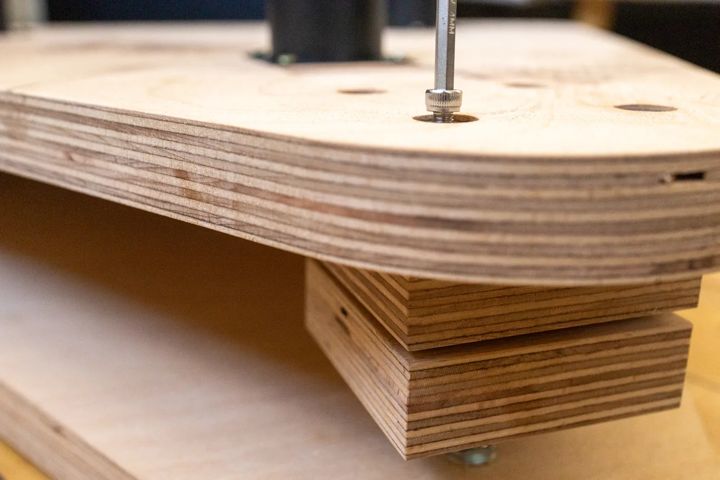
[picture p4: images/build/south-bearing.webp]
Montiertes Südlager aus Holzblock und Kugelgelenk
            
            <figcaption>Holzblock und Kugelgelenk bilden das Südlager</figcaption>
          </figure>
        </div>
      </section>

      <section class="eq-section soft" id="prinzip">
        <div class="eq-split">
          <div class="eq-split-copy">
            <p class="eq-kicker">Funktionsprinzip</p>
            <h2>Parallel zur Erdachse</h2>
            <p>
              Die bewegliche Tischplatte dreht sich um eine Achse, die parallel zur
              Erdachse ausgerichtet wird. Dadurch kompensiert die Plattform die
              scheinbare Bewegung des Sternenhimmels.
            </p>
            <ul class="eq-checks">
              <li>Nordlager über zwei Kreissegmente auf Linearwellen</li>
              <li>Südlager als definierter Dreh- und Neigungspunkt</li>
              <li>Feine Geschwindigkeitsregelung über Schrittmotor und Potentiometer</li>
            </ul>
          </div>
          <figure class="eq-diagram">
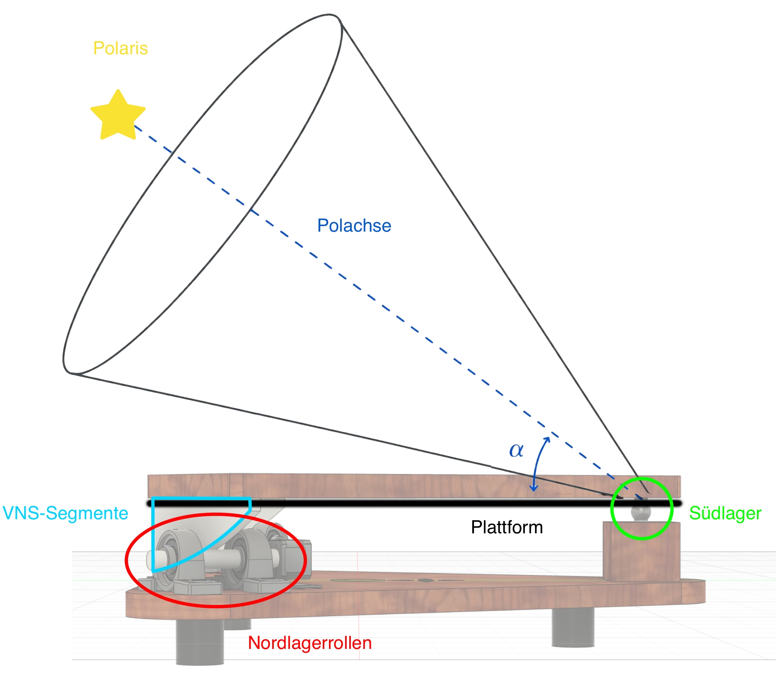
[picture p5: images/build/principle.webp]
Prinzip einer äquatorialen Plattform mit Polachse, Nordlager und Südlager
            
            <figcaption>Prinzipdarstellung aus der Bauanleitung</figcaption>
          </figure>
        </div>
      </section>

      <section class="eq-section" id="projektion" aria-labelledby="projektion-title">
        <div class="eq-section-heading">
          <h2 id="projektion-title">Vom Kreis zum Rollensegment</h2>
          <p>
            Zwei Projektionen bestimmen die Form: Der Breitengrad skaliert das
            VNS-Segment vertikal, der Rollenwinkel korrigiert die horizontale Länge.
          </p>
        </div>

        <div class="eq-projection" id="eq-projection-explainer">
          <div class="eq-projection-top">
            <p>
              Drehe das Modell frei im Raum oder wähle eine feste Ansicht. Die
              transparente Ebene zeigt, was von der räumlich gedrehten Ellipse in
              der Vorderansicht sichtbar bleibt.
            </p>
            <button class="eq-button eq-projection-play" id="eq-projection-play" type="button">
              Animation abspielen
            </button>
          </div>

          <div class="eq-projection-3d-shell">
            <div
              class="eq-projection-3d"
              id="eq-projection-3d"
              role="img"
              aria-label="Interaktives dreidimensionales Modell einer um Beta nach hinten gedrehten Ellipse mit rotem VNS-Segment und Projektionsebene"
            ><span class="eq-projection-3d-loading">3D-Modell wird geladen …</span></div>
            <div class="eq-projection-3d-status" aria-live="polite">
              <span class="eq-projection-3d-value" id="eq-projection-phi-value">A = r · cos(φ) = 0,643 r</span>
              <span class="eq-projection-3d-value" id="eq-projection-beta-value">B = r / cos(β) = 1,155 r</span>
            </div>
          </div>

          <div class="eq-projection-viewbar">
            <div class="eq-projection-view-buttons" aria-label="Kameraansicht">
              <button class="eq-projection-view-button" data-view="perspective" type="button" aria-pressed="true">Perspektive</button>
              <button class="eq-projection-view-button" data-view="front" type="button" aria-pressed="false">Vorderansicht</button>
              <button class="eq-projection-view-button" data-view="top" type="button" aria-pressed="false">Draufsicht</button>
            </div>
            <span class="eq-projection-hint">Ziehen zum Drehen · Mausrad oder Pinch zum Zoomen</span>
          </div>

          <div class="eq-projection-legend" aria-label="Legende">
            <span><i class="eq-projection-swatch" style="--swatch: var(--eq-warm)"></i>Ellipse im Raum</span>
            <span><i class="eq-projection-swatch" style="--swatch: var(--eq-red)"></i>VNS-Segment</span>
            <span><i class="eq-projection-swatch" style="--swatch: var(--eq-line)"></i>Projektionsebene</span>
          </div>

          <div class="eq-projection-controls">
            <div class="eq-projection-control">
              <div class="eq-projection-control-head">
                <label for="eq-projection-phi">Breitengrad φ</label>
                <output id="eq-projection-phi-output" for="eq-projection-phi">50°</output>
              </div>
              <input id="eq-projection-phi" type="range" min="0" max="70" step="1" value="50" />
            </div>
            <div class="eq-projection-control">
              <div class="eq-projection-control-head">
                <label for="eq-projection-beta">Rollenwinkel β</label>
                <output id="eq-projection-beta-output" for="eq-projection-beta">30°</output>
              </div>
              <input id="eq-projection-beta" type="range" min="0" max="45" step="1" value="30" />
            </div>
          </div>
          <div class="eq-projection-progress" aria-hidden="true"><span id="eq-projection-progress"></span></div>
        </div>
      </section>

      <section class="eq-section">
        <div class="eq-section-heading">
          <h2>Bauteile auf einen Blick</h2>
          <p>
            Die vollständige Stückliste enthält alle Schrauben und Bezugsquellen.
            Für das Grundprinzip reichen drei Baugruppen.
          </p>
        </div>
        <div class="eq-card-grid">
          <article class="eq-card">
            <span class="eq-card-label">Mechanik</span>
            <h3>Platten und Lagerung</h3>
            <ul>
              <li>Grund- und Tischplatte</li>
              <li>Zwei Kreissegmente</li>
              <li>2 Linearwellen Ø20 × 100 mm</li>
              <li>4 UCP204-Stehlager</li>
              <li>Kugelgelenk M10</li>
            </ul>
          </article>
          <article class="eq-card">
            <span class="eq-card-label">Antrieb</span>
            <h3>Riemen und Motor</h3>
            <ul>
              <li>NEMA17-Schrittmotor</li>
              <li>Winkelhalter</li>
              <li>GT2-Riemen und Pulleys</li>
              <li>Zwei Endstops</li>
              <li>Motorisierte Referenzfahrt</li>
            </ul>
          </article>
          <article class="eq-card">
            <span class="eq-card-label">Steuerung</span>
            <h3>PCB und Bedienung</h3>
            <ul>
              <li>Arduino Nano V3</li>
              <li>TMC2209-Treiber</li>
              <li>1,3-Zoll-OLED</li>
              <li>Schalter und Home-Taster</li>
              <li>10-kΩ-Potentiometer</li>
            </ul>
          </article>
        </div>
      </section>

      <section class="eq-section dark" id="antrieb">
        <div class="eq-section-heading">
          <h2>Präziser Antrieb, einfache Bedienung</h2>
          <p>
            Die eigene Steuerplatine verbindet Arduino, TMC2209, Display,
            Bedienelemente und Endstops zu einer kompakten Einheit.
          </p>
        </div>
        <div class="eq-dark-grid">
          <article class="eq-dark-card">
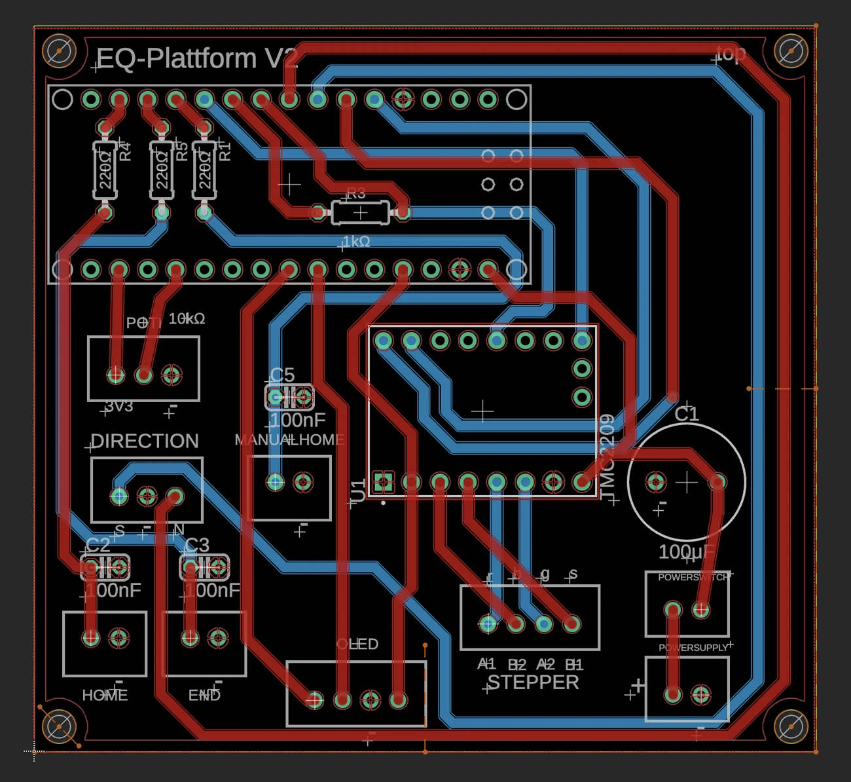
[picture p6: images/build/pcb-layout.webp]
Leiterplattenlayout der EQ Plattform
            
            <div class="eq-dark-card-copy">
              <h3>Steuerplatine</h3>
              <p>
                Alle Anschlüsse sind zentral geführt. Die Fertigungsdaten können
                direkt als ZIP heruntergeladen und bei einem Leiterplattenservice
                bestellt werden.
              </p>
            </div>
          </article>
          <article class="eq-dark-card">
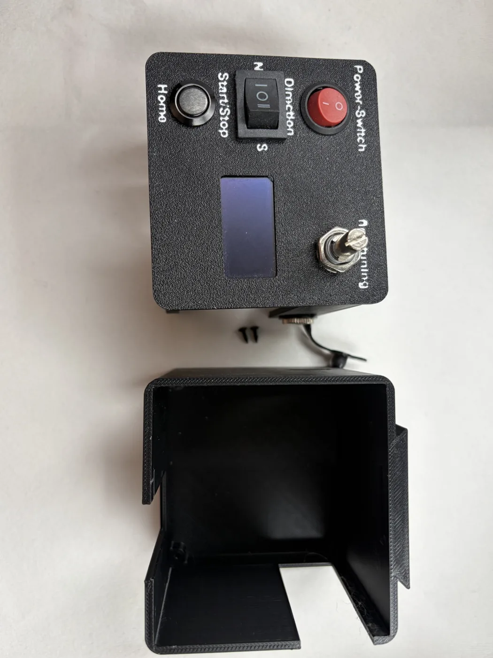
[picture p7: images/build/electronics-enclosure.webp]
Zweiteiliges 3D-gedrucktes Elektronikgehäuse
            
            <div class="eq-dark-card-copy">
              <h3>Gehäuse und Bedienung</h3>
              <p>
                Das 3D-gedruckte Gehäuse nimmt Platine, OLED, Schalter, Taster,
                Potentiometer und Stromanschluss auf und wird an der Plattform
                befestigt.
              </p>
            </div>
          </article>
        </div>
        <div class="eq-note">
          Beim Bestücken auf die Polarität des Elektrolytkondensators achten,
          offene Lötstellen isolieren und vor der Inbetriebnahme alle Verbindungen prüfen.
        </div>
      </section>

      <section class="eq-section">
        <div class="eq-section-heading">
          <h2>Standard oder Simple</h2>
          <p>
            Beide Mechanikvarianten verwenden dasselbe Funktionsprinzip und
            dieselbe Elektronik.
          </p>
        </div>
        <div class="eq-card-grid">
          <article class="eq-card">
            <span class="eq-card-label">Standard</span>
            <h3>Vollständige Ausführung</h3>
            <p>
              Mit Aussparungen für Libelle, Kompass und Windrose sowie
              Markierungen auf der Oberplatte.
            </p>
          </article>
          <article class="eq-card">
            <span class="eq-card-label">Simple</span>
            <h3>Reduzierte Fertigung</h3>
            <p>
              Weniger Aussparungen und Markierungen senken den Fräsaufwand,
              ohne das Grundprinzip zu verändern.
            </p>
          </article>
          <article class="eq-card">
            <span class="eq-card-label">Alternative</span>
            <h3>Aluminiumsegmente</h3>
            <p>
              Kreissegmente für Winkel von 40 bis 60 Grad stehen zusätzlich
              als STEP-Dateien für Aluminium bereit.
            </p>
          </article>
        </div>
      </section>

      <section class="eq-section soft" id="downloads">
        <div class="eq-section-heading">
          <h2>Alles zum Nachbauen</h2>
          <p>
            Anleitung lesen, Teile fertigen lassen und die fertige Firmware
            direkt im Browser installieren.
          </p>
        </div>
        <div class="eq-resource-grid">
          <a class="eq-resource" href="build_instructions/buildinstruction_EQ_Plattform.pdf">
            <span class="eq-resource-type">PDF · 32 Seiten</span>
            <span>
              <strong>Bauanleitung</strong>
              <small>Prinzip, Bauteile, Montage, Elektronik und Inbetriebnahme.</small>
            </span>
            <span class="eq-resource-arrow">→</span>
          </a>
          <a class="eq-resource" href="teileliste/">
            <span class="eq-resource-type">Web · CSV</span>
            <span>
              <strong>Stückliste</strong>
              <small>Übersichtlich sortiert mit Mengen und kurzen Händlerlinks.</small>
            </span>
            <span class="eq-resource-arrow">→</span>
          </a>
          <a class="eq-resource" href="https://github.com/MoMa13570/eq-plattform/tree/main/hardware/mechanical">
            <span class="eq-resource-type">STEP · STL · 3MF</span>
            <span>
              <strong>CAD-Dateien</strong>
              <small>Mechanikvarianten, Kreissegmente und Elektronikgehäuse.</small>
            </span>
            <span class="eq-resource-arrow">→</span>
          </a>
          <a class="eq-resource" href="hardware/circuitboard/EQ-Plattform%20Schaltplan_TMC2209%20v32_jlcpcb.zip">
            <span class="eq-resource-type">ZIP</span>
            <span>
              <strong>PCB-Fertigungsdaten</strong>
              <small>Datenpaket für die Herstellung der Steuerplatine.</small>
            </span>
            <span class="eq-resource-arrow">→</span>
          </a>
          <a class="eq-resource" href="https://github.com/MoMa13570/eq-plattform/releases/latest">
            <span class="eq-resource-type">Release</span>
            <span>
              <strong>Aktuelle Firmware</strong>
              <small>Geprüfte HEX-Datei für Arduino Uno und Nano.</small>
            </span>
            <span class="eq-resource-arrow">→</span>
          </a>
          <a class="eq-resource" href="flasher/">
            <span class="eq-resource-type">Chrome · Edge</span>
            <span>
              <strong>Firmware Flasher</strong>
              <small>HEX-Datei ohne Arduino IDE direkt per USB installieren.</small>
            </span>
            <span class="eq-resource-arrow">→</span>
          </a>
          <a class="eq-resource" href="https://mende-cnc.de/" target="_blank" rel="noopener">
            <span class="eq-resource-type">Beispielanbieter</span>
            <span>
              <strong>Teile fertigen lassen</strong>
              <small>Holzteile fräsen und Gehäuseteile per 3D-Druck herstellen lassen.</small>
            </span>
            <span class="eq-resource-arrow">↗</span>
          </a>
        </div>
      </section>

      <section class="eq-final">
        <div>
          <h2>Bereit für den Aufbau?</h2>
          <p>
            Die PDF führt durch alle Details. Für die Firmware reichen anschließend
            eine HEX-Datei, Chrome oder Edge und ein USB-Kabel.
          </p>
        </div>
        <a class="eq-button" href="build_instructions/buildinstruction_EQ_Plattform.pdf">Bauanleitung starten</a>
      </section>
    </main>

    <footer class="eq-footer">
      <span>EQ Plattform · Frank Sackenheim &amp; Moritz Mayer</span>
      <span><a href="https://github.com/MoMa13570/eq-plattform">GitHub Repository</a></span>
    </footer>
  </div>
</div>

<script type="module" src="projection-3d.js"></script>

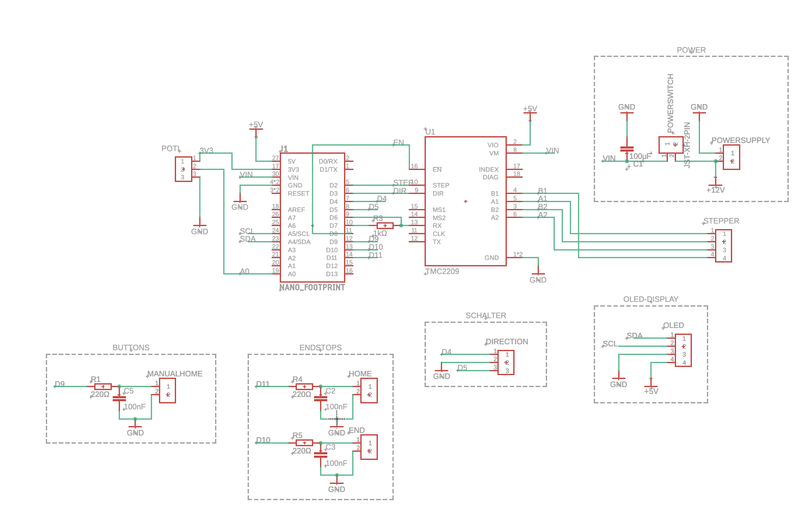
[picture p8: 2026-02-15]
hardware/circuitboard/Schematic.png

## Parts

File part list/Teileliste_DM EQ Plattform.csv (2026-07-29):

Anzahl | Name | Art-Nummer | Hersteller | Link
4 | Stehlager | UCP204 | SKF | https://www.kugellager-express.de/stehlager-lagerbock-stehlagereinheit-ucp204-welle-20-mm | https://www.amazon.de/gp/product/B0CY21PZ79/ref=ox_sc_act_title_5?smid=A3GOZYCJQ7M67E&psc=1
1 | Nema 17 Stepper | 17HE19-2004S | StepperOnline | https://www.omc-stepperonline.com/de/e-serie-nema-17-bipolar-59ncm-84oz-in-2a-42x48mm-4draehte-w-1m-kabel-verbinder-17he19-2004s
1 | Axialgelenkkopf M10 |  |  | https://www.fk-soehnchen.de/werkstatt/normteile/gelenkkoepfe-winkelgelenke/Axialgelenkkopf-M10-AG-IG-DIN-71802-CS-FKS-Trailer.html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
2 | Linearwelle 20mm," Länge 150mm | 35585Z | CNCShop | https://www.cncshop.at/Linearwelle-Praezisionswelle-O-20-mm-gehaertet-millimetergenauer-Zuschnitt | https://www.amazon.de/gp/product/B0DBX14SD8/ref=ox_sc_act_title_4?smid=A19TP5HTZOPTXA&th=1"
4 | Möbelfüße |  |  | https://www.amazon.de/NVIYAM-Verstellbare-HöHenverstellbar-Schrankbeine-HöHenverstellbare/dp/B0CXPNVP83
1 | 20mm Kompass |  |  | https://www.amazon.de/Vbest-life-umweltfreundlicher-Präzisionskompass-Outdoor-Aktivitäten/dp/B08VRJM3YF
1 | Dosenlibelle |  |  | https://www.amazon.de/Taskar-Große-Wasserwaage-Zielscheibendesign-Dosenlibelle/dp/B01KAIBO8I
8 | M5x30mm Zylinderkopf
2 | M5x18mm Zylinderkopf
10 | M5 Gewindeeinsätze
4 | M8x40mm Zylinderkopf
8 | M12x40mm Zylinderkopf
4 | M8 Gewindeeinstaz
1 | M10x25mm Zylinderkopf
8 | M12 Mutter
1 | M10 Gewindeeinsatz
für Platine
1 | Kippschalter 3polig |  |  | https://www.amazon.de/dp/B0FH6HK1MK?ref=ppx_yo2ov_dt_b_fed_asin_title
1 | Kippschalter 2polig |  |  | https://www.amazon.de/dp/B0CS32CZ4N?ref=ppx_yo2ov_dt_b_fed_asin_title&th=1
2 | 4.7kOhm Widerstand
1 | 100μF Elko
1 | Arduino nano
1 | TMC2009 Stepper driver
1 | 10kOhm Potentiometer |  |  | https://www.amazon.de/AZDelivery-Potentiometer-Schutzwiderstand-einstellbarem-Elektronik-Projekte/dp/B09Z727ZK3
1 | 1kOhm Widerstand
1 | DC Power Jack |  |  | https://www.amazon.de/dp/B09TVG21DR?ref_=ppx_hzsearch_conn_dt_b_fed_asin_title_8
 | Kabel
für Motor
1 | GT2 Motor-Pulley mit 16 Zähnen und 5mm Bohrung |  |  | https://www.ebay.de/itm/283315656377?var=585025474754
1 | GT2 Pulley mit 60Zähnen und 20mm Bohrung |  |  | https://www.ebay.de/itm/283315656377?var=585441520088
1 | GT2 Riemen 250mm |  |  | https://www.ebay.de/itm/283301228134?var=585116115700
4 | M4x10mm
4 | M4 Flügelmutter
1 | Nema17 Motorhalter |  |  | https://www.roboter-bausatz.de/p/cnc-motorhalter-fuer-nema-17-stahl-lackiert?sPartner=8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

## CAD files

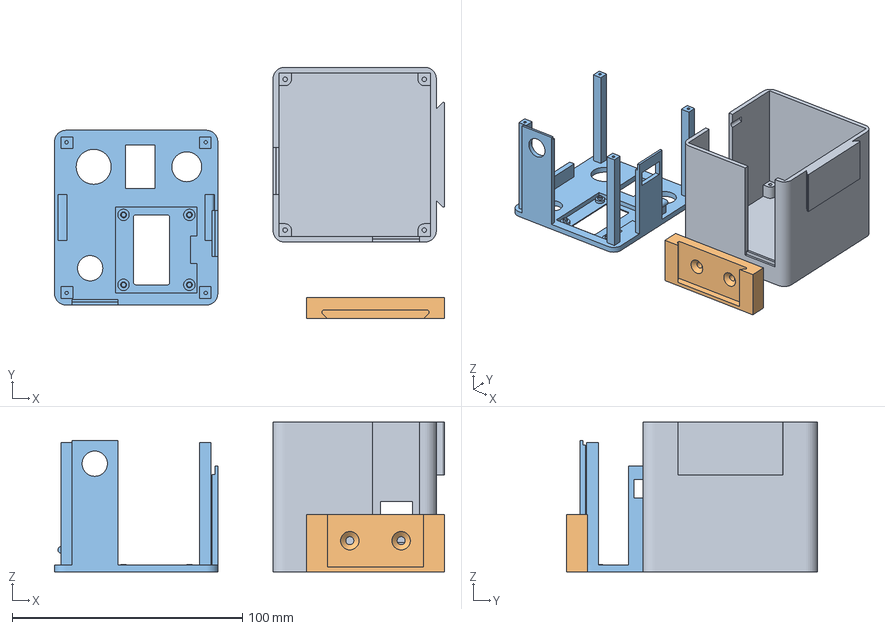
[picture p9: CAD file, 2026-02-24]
hardware/circuitboard/case/EQ-Plattform_PCB Case.3mf
169.5 x 109.3 x 65.0 mm
Case.stl
Montage.stl
Gehäuse_tmc2209.stl

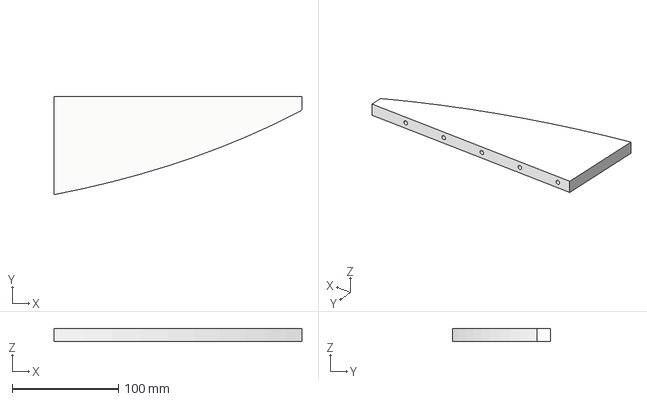
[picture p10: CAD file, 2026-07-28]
hardware/mechanical/Kreissegmente aus Aluminium/Segment_47°.step
233.9 x 92.8 x 12.0 mm

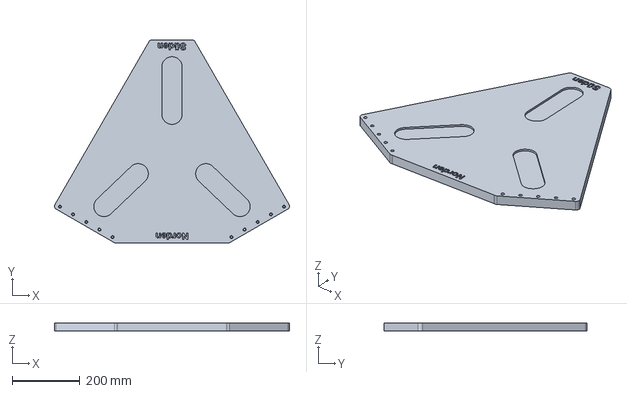
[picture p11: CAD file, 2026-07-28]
hardware/mechanical/normal/Oberplatte.step
695.0 x 601.6 x 25.0 mm

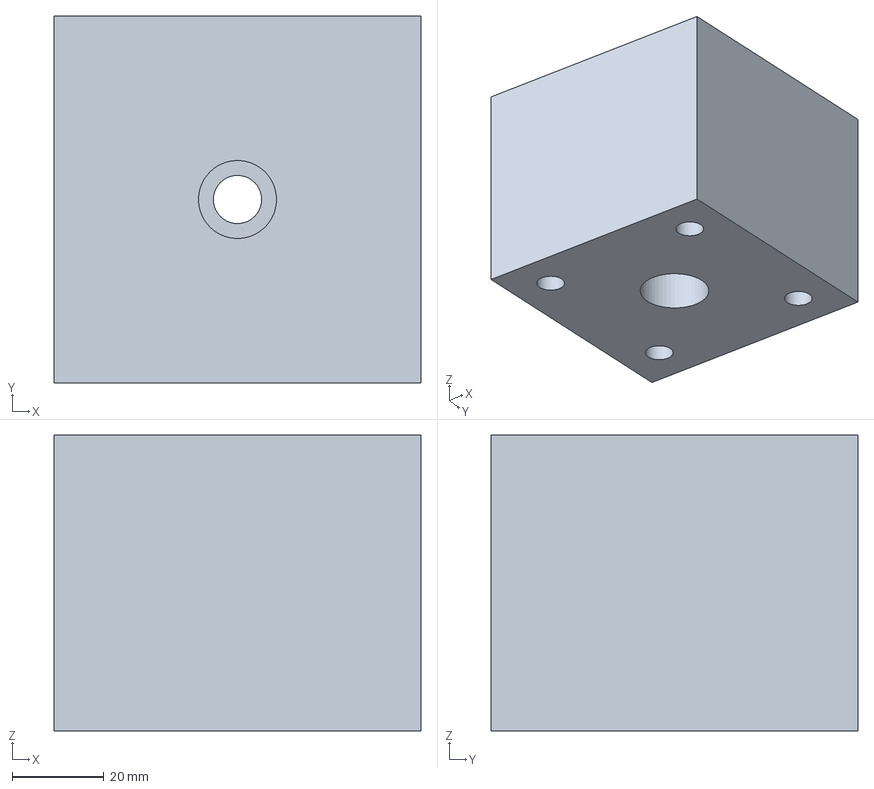
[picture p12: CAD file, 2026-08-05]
hardware/mechanical/Suedlager/Suedlager_42°.step
80.0 x 80.0 x 64.5 mm

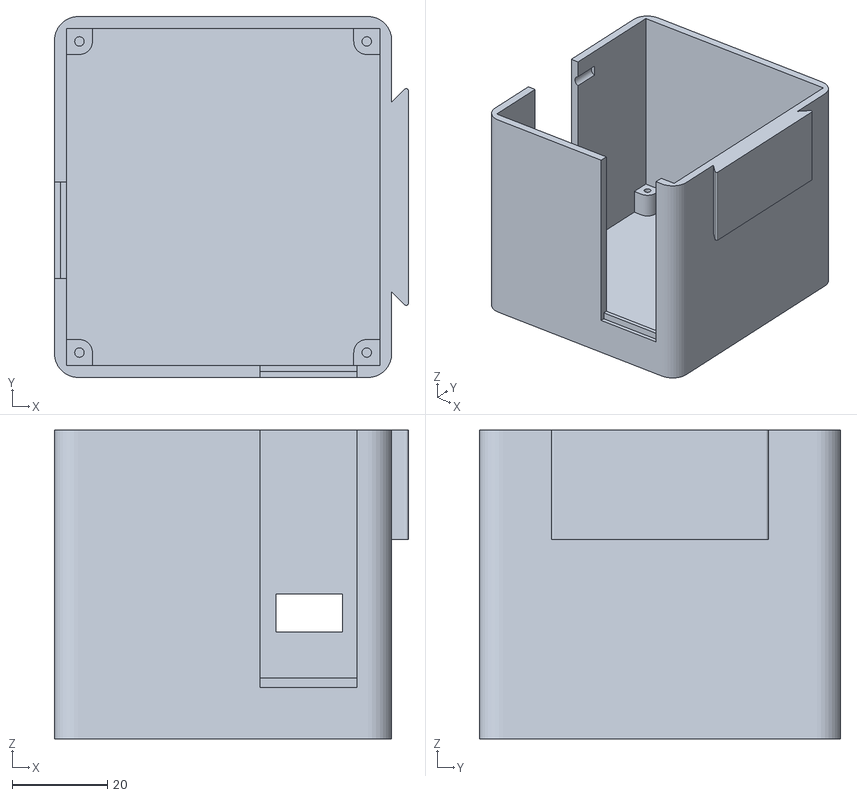
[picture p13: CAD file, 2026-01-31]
hardware/circuitboard/case/case.stl
74.5 x 76.0 x 65.0

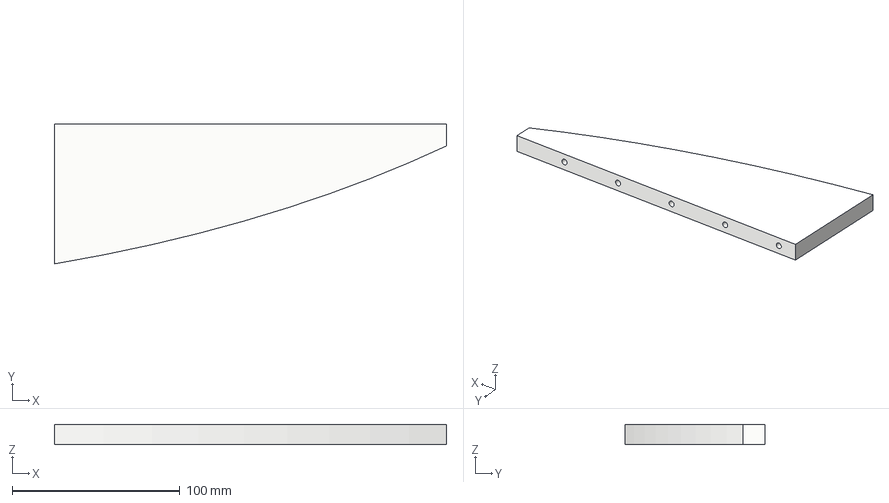
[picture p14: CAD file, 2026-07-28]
hardware/mechanical/Kreissegmente aus Aluminium/Segment_53°.step
233.9 x 83.4 x 12.0 mm

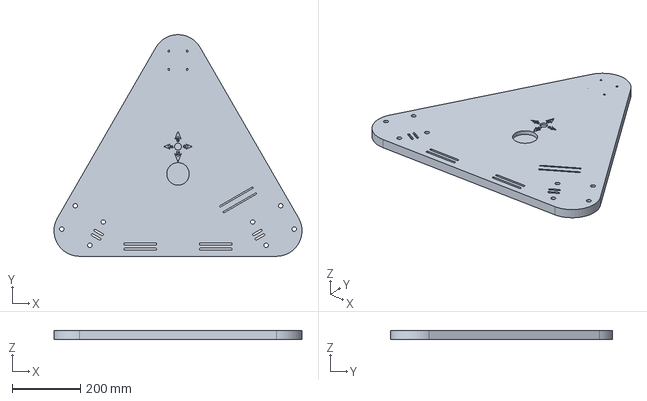
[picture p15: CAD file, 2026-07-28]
hardware/mechanical/normal/Unterplatte.step
726.7 x 649.4 x 25.0 mm

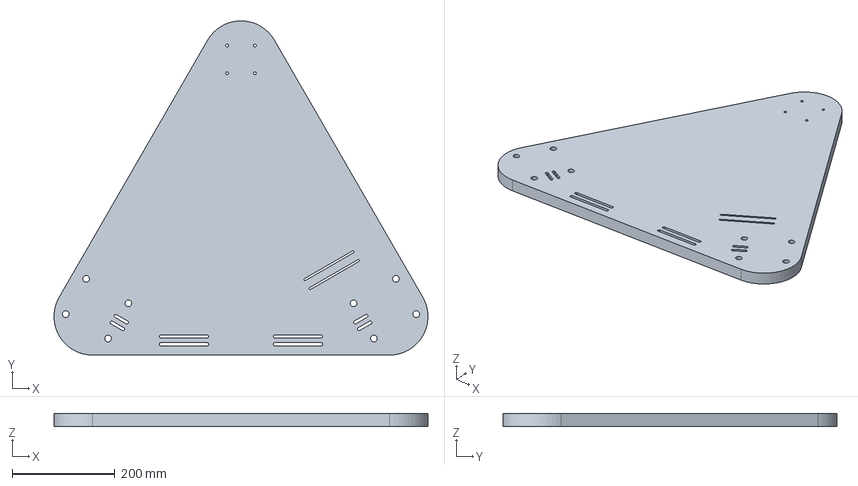
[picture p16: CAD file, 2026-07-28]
hardware/mechanical/simple/unterplatte_simple.step
726.7 x 649.4 x 25.0 mm

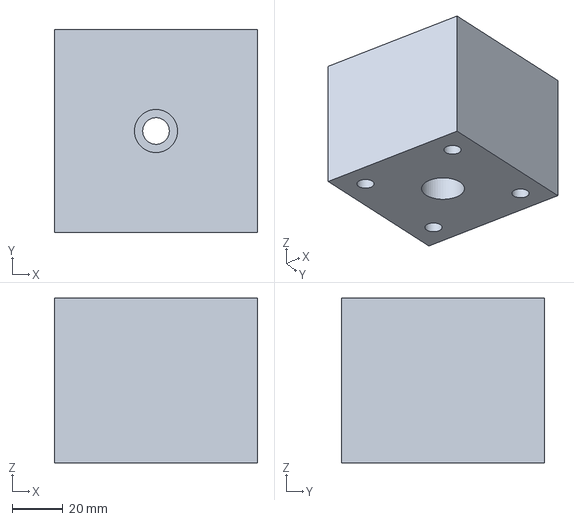
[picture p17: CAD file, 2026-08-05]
hardware/mechanical/Suedlager/Suedlager_43°.step
80.0 x 80.0 x 65.0 mm

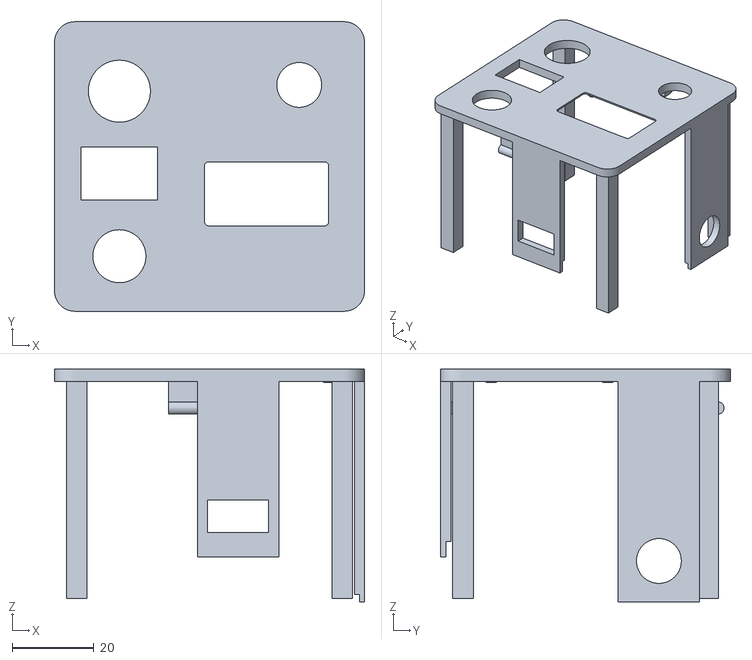
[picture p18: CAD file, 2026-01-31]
hardware/circuitboard/case/Gehäuse_tmc2209.stl
76.0 x 71.0 x 57.0

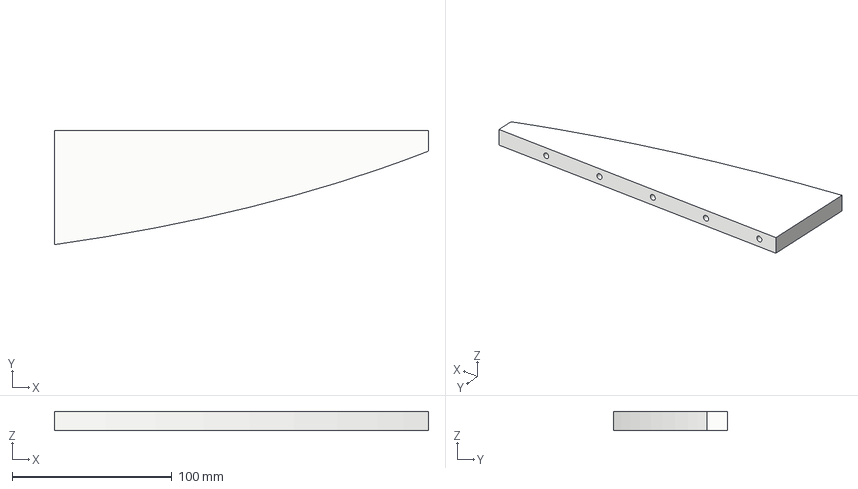
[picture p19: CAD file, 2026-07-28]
hardware/mechanical/Kreissegmente aus Aluminium/Segment_60°.step
233.9 x 71.5 x 12.0 mm

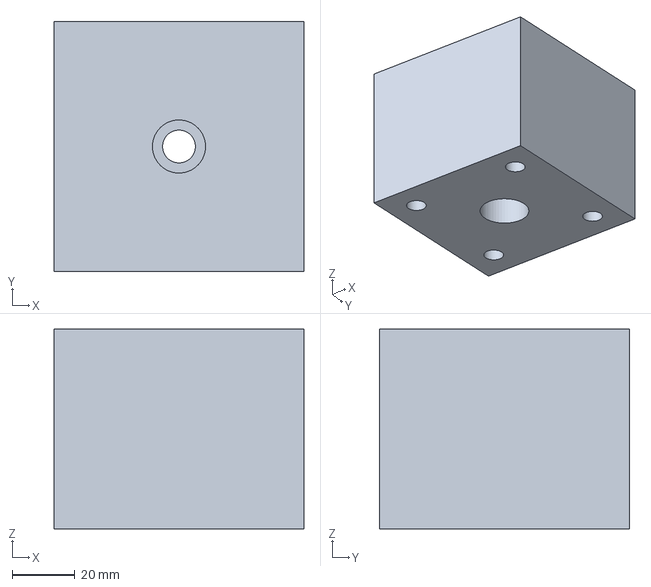
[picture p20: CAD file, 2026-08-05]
hardware/mechanical/Suedlager/Suedlager_41°.step
80.0 x 80.0 x 64.0 mm

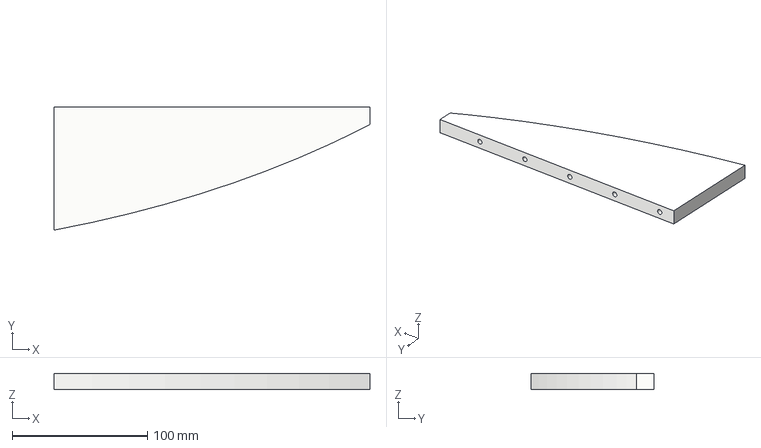
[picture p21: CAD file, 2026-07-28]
hardware/mechanical/Kreissegmente aus Aluminium/Segment_48°.step
233.9 x 91.3 x 12.0 mm

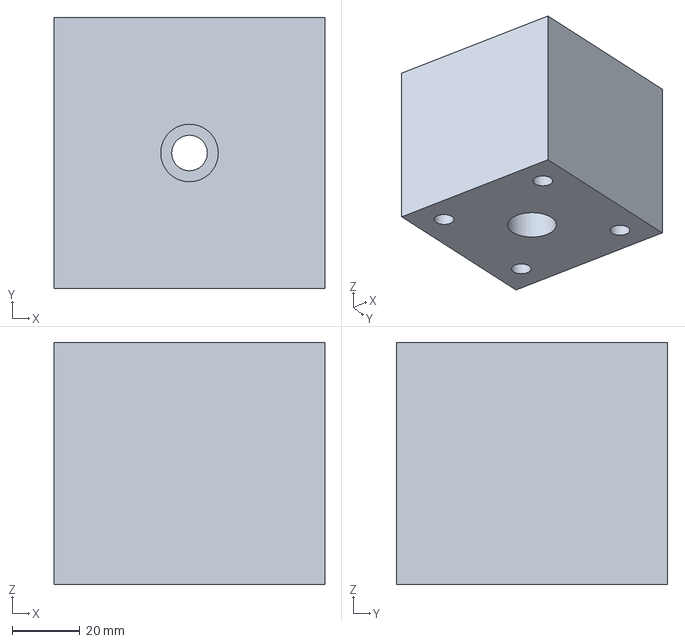
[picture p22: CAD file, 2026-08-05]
hardware/mechanical/Suedlager/Suedlager_56°.step
80.0 x 80.0 x 71.5 mm

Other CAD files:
hardware/mechanical/simple/Oberplatte_simple.step
hardware/mechanical/Kreissegmente aus Aluminium/Segment_56°.step
hardware/mechanical/Suedlager/Suedlager_55°.step
hardware/mechanical/Kreissegmente aus Aluminium/Segment_49°.step
hardware/mechanical/Kreissegmente aus Aluminium/Segment_40°.step
hardware/mechanical/Kreissegmente aus Aluminium/Segment_41°.step
hardware/mechanical/Kreissegmente aus Aluminium/Segment_42°.step
hardware/mechanical/Kreissegmente aus Aluminium/Segment_43°.step
hardware/mechanical/Kreissegmente aus Aluminium/Segment_44°.step
hardware/mechanical/Kreissegmente aus Aluminium/Segment_45°.step
hardware/mechanical/Kreissegmente aus Aluminium/Segment_46°.step
hardware/mechanical/Kreissegmente aus Aluminium/Segment_50°.step
hardware/mechanical/Kreissegmente aus Aluminium/Segment_51°.step
hardware/mechanical/Kreissegmente aus Aluminium/Segment_52°.step
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

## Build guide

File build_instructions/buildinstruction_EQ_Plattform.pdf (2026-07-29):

## Bauanleitung EQ-Plattform

Frank Sackenheim, Moritz Mayer

## Inhaltsverzeichnis

1 Einleitung | 3
2 Funktionsprinzip | 3
3 Benötigte Bauteile | 4
4 Zusammenbau | 7
5 Motorisierung | 13
6 Abschluss | 22
A Geometrische Herleitung der VNS-Nordsegmente | 23

## 1 Einleitung

Die äquatoriale Plattform ermöglicht die automatische Nachführung eines Dobson-Teleskops entsprechend der Erdrotation. Sie besteht aus einer festen Grundplatte und einer beweglich gelagerten Tischplatte, auf der das Teleskop positioniert wird.

bilder/gesamtansicht.jpg

Abbildung 1: Gesamtansicht der fertigen EQ-Plattform.

## 2 Funktionsprinzip

Die Plattform bewegt sich um eine Achse, die parallel zur Erdachse ausgerichtet ist. Dadurch kann die scheinbare Bewegung des Sternenhimmels kompensiert werden.

bilder/Schema.png

Abbildung 2: Prinzip einer äquatorialen Plattform mit Kegelschnitt.

Die genaue geometrische Herleitung der elliptischen Laufkontur sowie die daraus resultierenden Parameter für die Konstruktion in Fusion 360 sind in Anhang A beschrieben.

## 3 Benötigte Bauteile

### 3.1 CNC-gefräste Holzteile

- Grundplatte
- Tischplatte
- Zwei Kreissegmente; diese können alternativ auch aus Aluminium gefräst werden
- Holzblock für das Südlager

### 3.2 Mechanische Bauteile

- 2 Linearwellen mit 20 mm Durchmesser und 100 mm Länge
- 4 Stehlager UCP204
- Kugelgelenk M10

– https://www.fk-soehnchen.de/werkstatt/normteile/gelenkkoepfe-winkelgelenke/Axialgelenkkopf-M10-AG-IG-DIN-71802-CS-FKS-Trailer.html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 (https://www.fk-soehnchen.de/werkstatt/normteile/gelenkkoepfe-winkelgelenke/Axialgelenkkopf-M10-AG-IG-DIN-71802-CS-FKS-Trailer.html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)

- Gewindeeinsätze M5, M8 und M10
- Schrauben gemäß Stückliste: https://github.com/MoMa13570/eq-plattform/blob/main/BOM/Teileliste_DM%20EQ%20Plattform.csv (https://github.com/MoMa13570/eq-plattform/blob/main/BOM/Teileliste_DM%20EQ%20Plattform.csv)
- Verstellbare Möbelfüße

bilder/09_28_Bauteile.jpg

Abbildung 3: Übersicht aller benötigten Bauteile.

### 3.3 Antrieb

- NEMA-17-Schrittmotor

– https://www.amazon.de/STEPPERONLINE-Schrittmotor-55Ncm-Meter-3D-Drucker/dp/B0B93HTR87/ref=sr_1_4 (https://www.amazon.de/STEPPERONLINE-Schrittmotor-55Ncm-Meter-3D-Drucker/dp/B0B93HTR87/ref=sr_1_4)

- NEMA-17-Winkelhalter

– https://www.roboter-bausatz.de/p/cnc-motorhalter-fuer-nema-17-stahl-lackiert

- GT2-Pulley, 60 Zähne, 5 mm Bohrung

– https://www.ebay.de/itm/283315656377?var=585441520088

- GT2-Pulley, 60 Zähne, 20 mm Bohrung

– https://www.ebay.de/itm/283315656377?var=585025920459

- GT2-Riemen, 250 mm

– https://www.ebay.de/itm/283301228134?var=585116115700

- 4 M4×10 mm-Zylinderkopfschrauben
- 4 M4-Flügelmuttern
- Platine

– Die benötigten Bauteile und die Lötanleitung befinden sich in Abschnitt 5.2.

## 4 Zusammenbau

### 4.1 Montage der Möbelfüße

Befestigen Sie die Möbelfüße mit Holzschrauben an den vorgesehenen Ausfräsungen der Grundplatte.

bilder/09_29_MoÌĹbelfuÌĹÃ§e.jpg

Abbildung 4: Montage der Möbelfüße.

### 4.2 Montage der Stehlager

Montieren Sie die vier Stehlager zunächst nur handfest auf der Grundplatte.

bilder/09_30_Stehlager.jpg

Abbildung 5: Vormontage der Stehlager.

### 4.3 Einsetzen der Linearwellen

Schieben Sie die Linearwellen in die Stehlager ein und fixieren Sie sie anschließend mit den Madenschrauben.

bilder/09_31_Linearwellen.jpg

Abbildung 6: Einsetzen der Linearwellen.

### 4.4 Vorbereitung der Tischplatte

Setzen Sie den M10-Gewindeeinsatz in die vorgesehene Bohrung ein und schrauben Sie anschließend das Kugelgelenk ein.

bilder/09_33b_Kugelgelenk.jpg

Abbildung 7: Montage des Kugelgelenks.

### 4.5 Montage der Kreissegmente

Bohren Sie die benötigten Löcher, setzen Sie die M5-Gewindeeinsätze ein und verschrauben Sie anschließend die Kreissegmente mit der Tischplatte.

bilder/09_34_Kreissegmente.jpg

Abbildung 8: Montage der Kreissegmente.

### 4.6 Montage des Südlagers

Montieren Sie den Holzblock mit den M8-Gewindeeinsätzen und befestigen Sie ihn an der Grundplatte.

bilder/09_37_Block.jpg

bilder/09_38_Blockmontage.jpg

Abbildung 9: Montage des Südlagers.

## 5 Motorisierung

### 5.1 Schrittmotor mit Steuerplatine

Die Plattform kann mit einem Schrittmotor betrieben werden. Hierzu wird eine speziell entwickelte Steuerplatine verwendet, welche eine präzise elektronische Regelung der Nachführgeschwindigkeit ermöglicht.

Vorteile dieser Lösung:

- sehr genaue Nachführung,
- flexible Anpassung der Geschwindigkeit,
- Homesensor und Endstopp,
- Erweiterungsmöglichkeiten für zukünftige Funktionen.

Die Konstruktion, der Schaltplan sowie die Software für diese Motorvariante werden auf der Projekt-Homepage ausführlich dokumentiert. Die mechanische Montage unterscheidet sich lediglich in der Gestaltung der Motorhalterung und der Ankopplung an die Antriebswelle.

### 5.2 Platine

### 5.2.1 Benötigte Komponenten

Die Gerberdatei zur Fertigung der Platine ist im GitHub-Repository hinterlegt. Diese kann beispielsweise für wenige Euro bei JLCPCB bestellt werden. Dazu wird die Datei hochgeladen; anschließend können gegebenenfalls die Farbe und weitere Fertigungsoptionen gewählt werden.

Des Weiteren werden folgende Komponenten benötigt:

- Arduino Nano V3

– https://www.amazon.de/AZDelivery-AZ-Nano-V3-Board-Anschluss-kompatibel/dp/B0D8WDV1K7 (https://www.amazon.de/AZDelivery-AZ-Nano-V3-Board-Anschluss-kompatibel/dp/B0D8WDV1K7)

- TMC2209-Schrittmotortreiber

– https://www.amazon.de/TMC2209-Schrittmotortreiber-3D-Drucker-KÃhlkÃűrper-Unendliches/dp/B0D6R7YCRT (https://www.amazon.de/TMC2209-Schrittmotortreiber-3D-Drucker-Kühlkörper-Unendliches/dp/B0D6R7YCRT)

- 2 JST-XH, 3-polig

– https://www.reichelt.de/de/de/shop/produkt/jst_-_buchsengehaeuse_1x3-polig_-_xh-185086 (https://www.reichelt.de/de/de/shop/produkt/jst_-_buchsengehaeuse_1x3-polig_-_xh-185086)

– https://www.reichelt.de/de/de/shop/produkt/jst_-_stiftleiste_gerade_1x3-polig_-_xh-185074 (https://www.reichelt.de/de/de/shop/produkt/jst_-_stiftleiste_gerade_1x3-polig_-_xh-185074)

- 5 JST-XH, 2-polig

– https://www.reichelt.de/de/de/shop/produkt/jst_-_buchsengehaeuse_1x2-polig_-_xh-185085 (https://www.reichelt.de/de/de/shop/produkt/jst_-_buchsengehaeuse_1x2-polig_-_xh-185085)

– https://www.reichelt.de/de/de/shop/produkt/jst_-_stiftleiste_gerade_1x2-polig_-_xh-185073 (https://www.reichelt.de/de/de/shop/produkt/jst_-_stiftleiste_gerade_1x2-polig_-_xh-185073)

- 2 JST-XH, 4-polig

– https://www.reichelt.de/de/de/shop/produkt/jst_-_buchsengehaeuse_1x4-polig_-_xh-185087 (https://www.reichelt.de/de/de/shop/produkt/jst_-_buchsengehaeuse_1x4-polig_-_xh-185087)

– https://www.reichelt.de/de/de/shop/produkt/jst_-_stiftleiste_gerade_1x4-polig_-_xh-185075 (https://www.reichelt.de/de/de/shop/produkt/jst_-_stiftleiste_gerade_1x4-polig_-_xh-185075)

- 2 Buchsenleisten 1×8

– https://www.reichelt.de/de/de/shop/produkt/buchsenleisten_2_54_mm_1x08_gerade-119917

- 2 Buchsenleisten 1×16

– https://www.reichelt.de/de/de/shop/produkt/buchsenleisten_2_54_mm_1x16_gerade-119919

- 1 Widerstand mit 1 kΩ

– https://www.reichelt.de/de/de/shop/produkt/widerstand_kohleschicht_1_0_kohm_0207_250_mw_5_-1315 (https://www.reichelt.de/de/de/shop/produkt/widerstand_kohleschicht_1_0_kohm_0207_250_mw_5_-1315)

- 3 Widerstände mit 220 Ω

– https://www.reichelt.de/de/de/shop/produkt/widerstand_metallschicht_220_ohm_0207_0_6_0_1_-12875 (https://www.reichelt.de/de/de/shop/produkt/widerstand_metallschicht_220_ohm_0207_0_6_0_1_-12875)

- 1 Elektrolytkondensator mit 100 µF

– https://www.reichelt.de/de/de/shop/produkt/elko_radial_100_f_16_v_rm_2_5_85_c_2000_h_20_-22835 (https://www.reichelt.de/de/de/shop/produkt/elko_radial_100_f_16_v_rm_2_5_85_c_2000_h_20_-22835)

- 3 Keramikkondensatoren mit 100 nF

– https://www.reichelt.de/de/de/shop/produkt/tantalkondensator_100_nf_35_v-246447

- 1 dreipoliger Kippschalter

– https://www.amazon.de/dp/B0FH6HK1MK

- 1 zweipoliger Kippschalter

– https://www.amazon.de/dp/B0CS32CZ4N

- 1 zweipoliger Drucktaster

– https://www.amazon.de/dp/B0C3C1BL5Q

- 1 Mehrgang-Potentiometer mit 10 kΩ

– https://www.amazon.de/AZDelivery-Potentiometer-Schutzwiderstand-einstellbarem-Elektronik-Projekte/dp/B09Z727ZK3 (https://www.amazon.de/AZDelivery-Potentiometer-Schutzwiderstand-einstellbarem-Elektronik-Projekte/dp/B09Z727ZK3)

- Kabel, idealerweise in verschiedenen Farben
- 1 OLED-Display mit 1,3 Zoll

– https://www.amazon.de/AZDelivery-Display-Arduino-Raspberry-Gratis/dp/B078J78R45

- 2 Mikroschalter

– https://www.amazon.de/dp/B07F9QKTQQ

- 1 DC-Buchse

– https://www.amazon.de/dp/B09TVG21DR

Alternativ kann anstelle der einzelnen JST-XH-Stecker ein Set mit passender Crimpzange genutzt werden:

https://www.amazon.de/PEBA-Crimpzange-Stecker-Crimpzangen-EI-Serie/dp/B0CT5TP9PC

Alternativ können Dupont-Stecker verwendet oder die Kabel direkt an die Platine gelötet werden. Empfohlen wird jedoch die Verbindung über JST-XH-Stecker.

### 5.2.2 Löten der Platine

Wenn alle Komponenten und die Platine vorliegen, kann mit dem Bestücken und Verlöten begonnen werden. Dazu empfiehlt es sich, eine dritte Hand oder eine PCB-Löthilfe zu verwenden.

Nun folgt eine Schritt-für-Schritt-Anleitung für das Bestücken und Verlöten der Platine:

- Bestücken Sie zunächst alle Widerstände und Keramikkondensatoren, indem Sie die Drahtbeinchen in die entsprechenden Löcher einführen. Biegen Sie die Beinchen auf der Rückseite leicht auseinander, damit die Bauteile selbstständig halten. Siehe Abbildung 11. Drehen Sie anschließend die Platine auf die Lötseite, verlöten Sie die Bauteile und schneiden Sie die überstehenden Drähte mit einem Seitenschneider ab.
- Bestücken Sie anschließend den Elektrolytkondensator. Achten Sie hierbei unbedingt auf die Polarität. Auf dem Kondensator ist der Minuspol markiert; die Polarität ist auch auf der Platine angegeben. Siehe Abbildung 12b.
- Bestücken Sie die JST-XH-Stiftleisten nacheinander. Es hilft, die Leisten beim Löten leicht zu fixieren, damit sie nicht aus der Platine herausfallen.
- Bestücken Sie anschließend die Buchsenleisten für den Arduino und den Motortreiber. Auch diese sollten während des Lötens fixiert werden.
- Löten Sie, falls noch nicht vorhanden, die Stiftleisten an den Arduino Nano und den TMC2209. Stecken Sie beide anschließend an den vorgesehenen Positionen auf die Platine.
- Schneiden Sie die Kabel des Drucktasters und des dreipoligen Kippschalters auf Länge und crimpen Sie die JST-XH-Stecker an.
- Bereiten Sie entsprechend lange Kabel für den zweipoligen Kippschalter und das Potentiometer vor. Löten Sie jeweils ein Kabelende an die vorgesehenen Anschlüsse. Am anderen Ende wird der passende JST-XH-Stecker angecrimpt. Achten Sie beim Potentiometer darauf, dass die Anschlussbelegung zur Belegung der Platine passt. Siehe Abbildung 12a.
- Bereiten Sie das Kabel für das Display vor. An einer Seite befindet sich ein Dupont-Stecker, an der anderen Seite ein JST-XH-Stecker.
- Schneiden Sie entsprechend lange Kabel für die beiden Endschalter zu. Verlöten Sie jeweils ein Ende mit den Endschaltern und crimpen Sie an das andere Ende den JST-XH-Stecker. Das Signalkabel wird mit dem Anschluss „Normally Open“ beziehungsweise „NO“ verbunden. Das zweite Kabel wird an „COM“ angeschlossen. Siehe Abbildung 12c.
- Schneiden Sie die Kabel für die DC-Buchse zurecht und löten Sie je ein Kabel an die vorgesehenen Anschlüsse. Auf der anderen Seite wird der JST-XH-Stecker angecrimpt.

Hinweis: An offenen Lötstellen, beispielsweise an den Endschaltern oder am Potentiometer, sollte ein Schrumpfschlauch über Kabel und Lötstelle gezogen werden.

Ein Bild der Bestückung ist in Abbildung 10 als 2D- und 3D-Ansicht dargestellt.

bilder/PCB_2D.png | bilder/PCB_3D.jpeg

Abbildung 10: 2D- und 3D-Ansicht der Platine.

bilder/Bauteilbeinchenbiegen.jpeg

Abbildung 11: Biegen der Bauteilbeinchen.

bilder/poti.jpg

(a) Pinbelegung des Potentiometers.

bilder/Elko.jpeg

(b) Polarität des Elektrolytkondensators.

bilder/Endstop.png

(c) Pinbelegung des Mikroschalters.

Abbildung 12: Anschluss- und Bestückungshinweise für die Elektronik.

### 5.3 Gehäuse für die Elektronik

Um die Elektronik unterzubringen, wurde ein entsprechendes Gehäuse konstruiert, das mit einem 3D-Drucker gefertigt werden kann. Die zugehörigen STL-Dateien sowie ein Bambu-Studio-Projekt befinden sich im GitHub-Repository:

https://github.com/MoMa13570/eq-plattform/tree/main/hardware/circuitboard/case

Wenn kein 3D-Drucker vorhanden ist, können die Teile alternativ bei JLC3DP oder einem anderen Onlineanbieter bestellt werden.

Das Gehäuse besteht aus zwei Teilen, siehe Abbildung 13a: einem Deckel, an dem die Platine verschraubt und die übrigen Bauteile montiert werden, sowie dem eigentlichen Gehäuseunterteil. Das Display wird vorzugsweise mit Heißkleber befestigt. Der fertig bestückte Deckel wird anschließend in das Unterteil eingeschoben.

Vorgehensweise:

- Kleben Sie das Display von unten mit Heißkleber in den Deckel.
- Schieben Sie die beiden Kippschalter und den Druckknopf von oben in den Deckel, bis diese einrasten.
- Schieben Sie das Potentiometer von unten durch die vorgesehene Bohrung und sichern Sie es von oben mit einer Mutter.
- Stecken Sie die DC-Buchse von außen durch die vorgesehene Öffnung und sichern Sie sie von innen mit einer Mutter.
- Stecken Sie alle Stecker auf die Platine.
- Schrauben Sie die Platine am Deckel fest.
- Stecken Sie das Motorkabel des NEMA-17-Motors ein und führen Sie es durch die vorgesehene Aussparung nach außen.
- Führen Sie die Kabel der Endschalter ebenfalls durch die entsprechenden Aussparungen.
- Schieben Sie den Deckel in das Gehäuseunterteil, bis er einrastet. Siehe Abbildung 13c.

bilder/case.jpeg

(a) Gehäuseteile.

bilder/case_top.jpeg

(b) Bauteile im Deckel des Gehäuses.

bilder/case_comb.jpeg

(c) Fertiges Gehäuse.

Abbildung 13: Übersicht der Gehäuseteile und des fertigen Gehäuses.

Das Gehäuse besitzt einen Schwalbenschwanz und kann mit einer entsprechenden Montageplatte an der Plattform befestigt werden.

bilder/gehÃďuse_montage.jpg

Abbildung 14: Montiertes Gehäuse.

### 5.4 Montage des Motors

Der NEMA-17-Schrittmotor wird an einen Winkelhalter geschraubt. Der Winkelhalter wird anschließend an der vorgesehenen Position auf der Bodenplatte der EQ-Plattform befestigt.

Danach wird das Riemenrad auf der Motorwelle montiert. Ein weiteres Riemenrad wird auf der Linearwelle befestigt. Anschließend wird der Riemen um beide Riemenräder gelegt. Zum Spannen des Riemens wird der Motor im Langloch verschoben und danach festgeschraubt.

bilder/Motormontage.jpg

Abbildung 15: Montierter Motor an der Bodenplatte.

### 5.5 Montage der Endschalter

Montieren Sie die Endschalter auf den entsprechenden Halterungen und verschrauben Sie diese anschließend an den vorgesehenen Positionen auf der Bodenplatte.

bilder/Endstopmontage.jpg

Abbildung 16: Montierte Endschalter.

## 6 Abschluss

Überprüfen Sie abschließend alle Schraubverbindungen und testen Sie die Leichtgängigkeit der Plattform. Nach erfolgreicher Funktionsprüfung kann die Polausrichtung und Inbetriebnahme erfolgen.

bilder/fertig.jpg

Abbildung 17: Fertig montierte EQ-Plattform.

## A Geometrische Herleitung der VNS-Nordsegmente

A.1 Ziel und Modellannahmen

Gesucht ist die Kontur eines vertikalen Nordsegments einer VNS-EQ-Plattform.

Die Konstruktion basiert auf einem Kreis mit dem Radius R, dessen Mittelpunkt im Südlager liegt. Durch die Projektion des geneigten Kreissegments auf die senkrechte Ebene des VNS-Segments erscheint der Kreis als Ellipse.

Der verwendete Kreisbogen wird dabei

- in vertikaler Richtung mit dem Faktor cos φ gestaucht und
- in horizontaler Richtung mit dem Faktor 1/ cos β gestreckt.

Dabei bezeichnet

- φ den geografischen Breitengrad,
- β die Verdrehung des Segments gegenüber der Horizontalen,
- τN die gesamte nutzbare Nachführzeit von einem Ende des Nutzbereichs bis zum anderen.

Die mathematisch festgelegte Kante ist ausschließlich die elliptische Lauffläche. Die übrige mechanische Kontur des Segments kann anhand der Befestigung und der erforderlichen Steifigkeit frei gestaltet werden.

A.2 Geometrische Anschauung der Projektion

Ein Kreis erscheint nur dann als Kreis, wenn seine Ebene senkrecht zur Blickrichtung steht.

Wird dieselbe Kreisfläche unter einem schrägen Betrachtungswinkel gesehen oder orthogonal auf eine anders ausgerichtete Ebene projiziert, bleibt ihre Ausdehnung in einer Richtung unverändert, während sie in der dazu senkrechten Richtung verkürzt erscheint.

Die Projektion eines Kreises ist deshalb im Allgemeinen eine Ellipse.

Zur Veranschaulichung sei ein Kreis mit Radius R betrachtet. Seine Ebene werde um einen Winkel α gegenüber der Bildebene geneigt. Die horizontale Ausdehnung bleibt bei geeigneter Wahl der Drehachse unverändert, während die vertikale Ausdehnung mit dem Faktor cos α verkürzt wird.

Damit werden aus den ursprünglichen Kreisradien

a = R, | (1)
b = R cos α. | (2)

Die projizierte Kurve besitzt somit die Parametergleichung

x(t) = R cost, | (3)
y(t) = R cos α sin t. | (4)

Einsetzen in die Ellipsengleichung ergibt

x

2
R²

+

y

2
R² cos² α
| | = 1. | (5)

Damit ist gezeigt, dass die orthogonale Projektion des geneigten Kreises eine Ellipse mit den Halbachsen

a = R | und | b = R cos α | (6)

ergibt.

Projektion

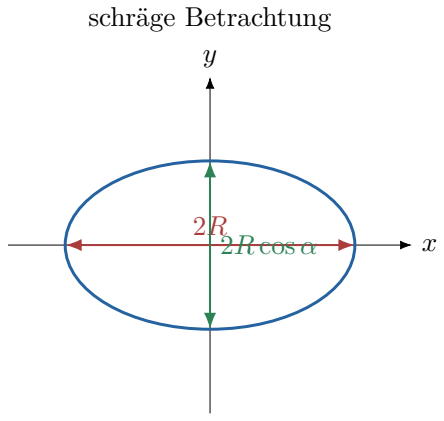
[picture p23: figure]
2R 2R cos α; schräge Betrachtung

Ellipse

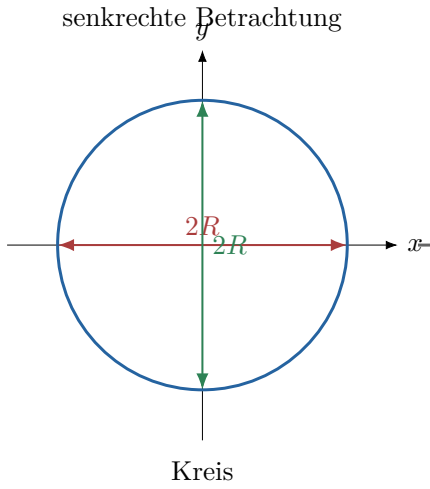
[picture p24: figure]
senkrechte Betrachtung; Kreis

Abbildung 18: Ein Kreis erscheint bei schräger Betrachtung beziehungsweise bei orthogonaler Projektion auf eine anders ausgerichtete Ebene als Ellipse. Die Ausdehnung parallel zur Drehachse bleibt unverändert, während die dazu senkrechte Ausdehnung mit cos α verkürzt wird.

Die VNS-Konstruktion nutzt genau dieses Prinzip. Das ursprünglich geneigte Kreissegment wird auf eine senkrechte Segmentebene projiziert.

Dabei wird seine vertikale Koordinate mit dem Faktor

cos φ | (7)

multipliziert. Aus dem Kreissegment entsteht dadurch ein Ellipsensegment.

Die zusätzliche horizontale Streckung mit

1
cos β

(8)

ist keine Folge des Betrachtungswinkels, sondern kompensiert die spätere Verdrehung des einzelnen VNS-Segments um den Winkel β.

A.3 Koordinatensystem und Rollenlage

Der Ursprung des Koordinatensystems liegt im Mittelpunkt des Südlagers.

Die Achsenrichtungen werden wie folgt festgelegt:

- positive x-Richtung nach rechts,
- positive y-Richtung nach oben.

Die betrachtete Rolle liegt rechts unterhalb des Südlagers.

Die Größen xR und yR werden als positive Abstandsbeträge definiert. Der Rollenmittelpunkt besitzt daher die Koordinaten

rR =

xR
−yR

!
, | (9)

wobei

xR > 0, | yR > 0 | (10)

gelten.

Der Abstand vom Südlager zum Rollenmittelpunkt beträgt

R =

q
x

2
R + y

2
R
. | (11)

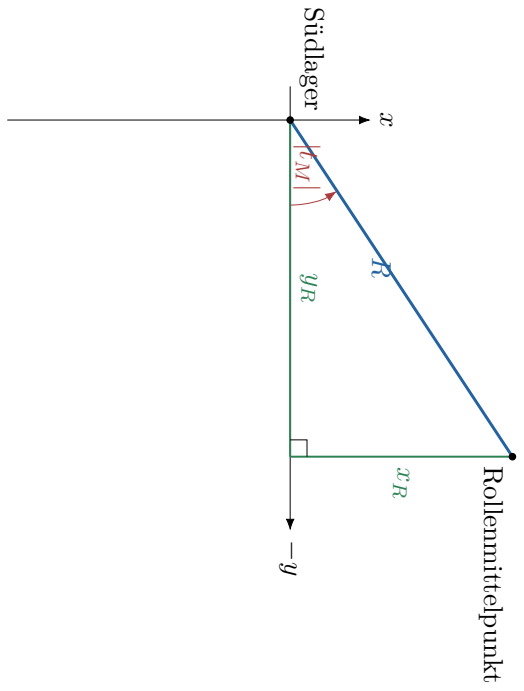
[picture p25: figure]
Südlager; Rollenmittelpunkt

Abbildung 19: Rechtwinklige Zerlegung der Rollenposition relativ zum Südlager. Die positive x-Richtung zeigt nach rechts, die positive y-Richtung nach oben. Der Rollenmittelpunkt liegt deshalb in negativer y-Richtung.

Da der Rollenmittelpunkt rechts unterhalb des Südlagers liegt, ist sein Parameterwinkel gegenüber der positiven x-Achse negativ.

Damit gilt

tM = − arctan

yR
xR
. | (12)

Falls die Rollenlage ideal aus dem Radius R und der Segmentverdrehung β aufgebaut wird, gilt

xR = R sin β, | (13)
yR = R cos β. | (14)

Einsetzen in die Winkeldefinition liefert

tM = − arctan

R cos β
R sin β
(15)

= − arctan

cos β
sin β
. | (16)

Für den betrachteten Bereich

0 < β < π
2

(17)

folgt

tM = β −

π
2
. | (18)

Diese Beziehung gilt unter der Annahme, dass die Verbindungslinie vom Südlager zum Rollenmittelpunkt senkrecht zur Segmentrichtung steht.

A.4 Ausgangskreis

Der Ausgangskreis wird mit dem Parameterwinkel t beschrieben durch

xK(t) = R cost, | (19)
yK(t) = R sin t. | (20)

Da die Rolle rechts unterhalb des Südlagers liegt, werden für den betrachteten Kreisbogen negative Parameterwinkel verwendet:

−

π
2
< t < 0. | (21)

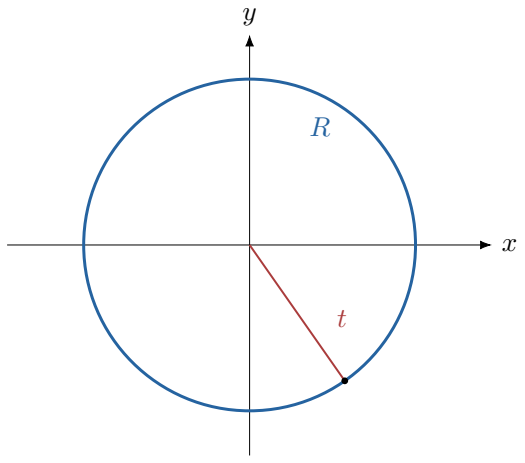
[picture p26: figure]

Abbildung 20: Parametrisierung des ursprünglichen Kreises. Der betrachtete Kreisbogen liegt rechts unterhalb des Südlagers und damit in negativer y-Richtung.

A.5 Transformation zum VNS-Segment

Die vertikale Projektion des Kreissegments liefert die Stauchung

sy = cos φ | . | (22)

Die Verdrehung des einzelnen Segments um den Winkel β wird durch die horizontale Streckung

sx =

1
cos β

(23)

kompensiert.

Damit lauten die Halbachsen der resultierenden Ellipse

a =

R
cos β
| , | (24)
b = R cos φ | . | (25)

Die transformierte Laufkurve ist somit

x(t) = a cost =

R
cos β
cost | , | (26)
y(t) = b sin t = R cos φ sin t | . | (27)

Für negative Winkel

−

π
2
< t < 0 | | (28)

ist

sin t < 0, | (29)

sodass der betrachtete Segmentbogen in negativer y-Richtung liegt.

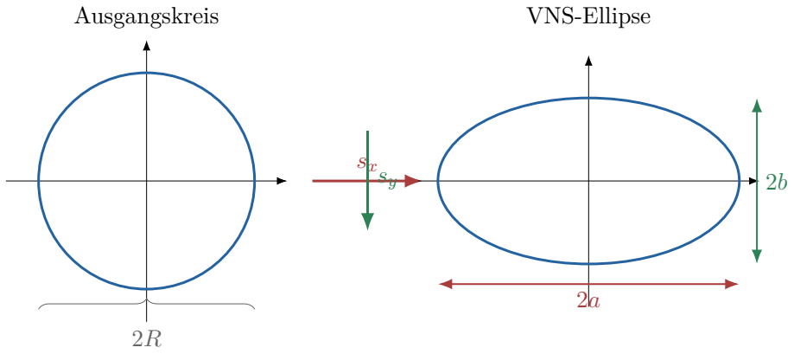
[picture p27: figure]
Ausgangskreis; VNS-Ellipse

Abbildung 21: Affine Transformation des Ausgangskreises zur VNS-Ellipse. Die vertikale Koordinate wird mit cos φ gestaucht, die horizontale Koordinate mit 1/ cos β gestreckt.

A.6 Nachführzeit und Winkelbereich

Die siderische Winkelgeschwindigkeit wird durch die Konstante

ωsid =

2π

Tsid

(30)

definiert, wobei Tsid die Dauer eines siderischen Tages bezeichnet.

Für die gesamte nutzbare Nachführzeit τN , gemessen von einem Ende des Nutzbereichs bis zum anderen, ergibt sich der nutzbare Winkel

∆tN = ωsidτN | . | (31)

Mit einem Reservewinkel tR an beiden Enden lautet der gesamte geometrische Segmentwinkel

∆tG = ∆tN + 2tR | . | (32)

Da τN bereits die vollständige Laufzeit von Rand zu Rand bezeichnet, wird ∆tN nicht noch einmal verdoppelt.

Die Grenzen des verwendeten Ellipsenbogens sind

tS = tM −

∆tG
2
, | (33)

tE = tM +

∆tG
2
. | (34)

x

y

tS

tM

tE

∆tG

Abbildung 22: Lage des verwendeten Segmentbogens im rechten unteren Quadranten der transformierten Ellipse.

A.7 Punkte für die Fusion-Konstruktion

Die Endpunkte des Laufbogens sind

PS =

a costS
b sin tS

!
, | (35)

PE =

a costE
b sin tE

!
. | (36)

Der mittlere Kontaktbereich liegt bei

PM =

a costM
b sin tM

!
. | (37)

Für eine rein parametrische Fusion-Skizze wird zunächst die vollständige Ellipse mit den Halbachsen a und b angelegt.

Anschließend werden die Punkte PS und PE auf dem rechten unteren Ellipsenzweig positioniert. Die Ellipse wird an diesen Punkten geteilt, und ausschließlich der Bogen zwischen beiden Punkten wird als Lauffläche verwendet.

A.8 Mechanische Segmentkontur

Nur die Laufkante ist astronomisch-geometrisch festgelegt.

Die übrige Kontur kann anhand der mechanischen Anforderungen gestaltet werden. Eine robuste Grundform besteht aus

- dem Ellipsenbogen von PS bis PE,
- zwei Seitenlinien,
- einer geraden Befestigungskante.

Die Segmenthöhe hS und die Materialdicke dS sind freie Konstruktionsparameter.

hS

VNS-Lauffläche

Befestigungskante

Abbildung 23: Prinzipielle mechanische Kontur eines VNS-Segments. Die astronomisch relevante Lauffläche liegt unten in negativer y-Richtung. Die übrige Kontur kann entsprechend den mechanischen Anforderungen frei gestaltet werden.

A.9 Rollenradius und exakter Kontakt

Der Rollendurchmesser beeinflusst die Form der VNS-Ellipse nicht.

Er wird nur benötigt, wenn die genaue Lage des Rollenmittelpunkts gegenüber dem Kontaktpunkt bestimmt werden soll.

Für die Ellipse

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
= 1 | (38)

ist eine nicht normierte Normalenrichtung

n(t) =

cost/a

sin t/b!
. | (39)

Die Einheitsnormale lautet

nb(t) = n(t)
∥n(t)∥
. | (40)

Für einen Rollenradius rW liegt der Rollenmittelpunkt bei exaktem Tangentialkontakt auf

cW (t) = p(t) ± rW nb(t). | (41)

Diese Offsetbeziehung ist nur erforderlich, wenn der Kontakt zwischen Rolle und Segment einschließlich des Rollenradius konstruktiv ausgewertet werden soll.

Für die Vogel-Projektion und die reine Segmentkontur genügen

R, | φ, | β, | tM, | τN , | tR.

A.10 | Zusammenfassung der Parameter
Symbol | Bedeutung beziehungsweise Beziehung
R | Referenzradius vom Südlager zur Rollenlage
φ | geografischer Breitengrad
β | Verdrehwinkel des Segments zur Horizontalen
xR, yR | positive Beträge der Rollenposition relativ zum Südlager

rR

| xR, −yR

T

tM | − arctan(yR/xR)
a | R/ cos β
b | R cos φ
Tsid | Dauer des siderischen Tages
ωsid | 2π/Tsid
τN | gesamte nutzbare Nachführzeit von Rand zu Rand
∆tN | ωsidτN
tR | Reservewinkel je Segmentende
∆tG | ∆tN + 2tR
tS | tM − ∆tG/2
tE | tM + ∆tG/2
hS | mechanische Segmenthöhe
dS | Materialdicke
A.11 | Empfohlene Fusion-Abhängigkeiten

Die für Fusion geeignete Abhängigkeitskette lautet

R =

q
x

2
R + y

2
R

,

tM = − arctan

yR
xR

= − arctan

R cos β
R sin β

= − arctan

cos β
sin β
,

a =

R
cos β

,

b = R cos φ,

ωsid =

2π

Tsid

,

∆tN = ωsidτN ,

∆tG = ∆tN + 2tR,

tS = tM −

∆tG
2

,

tE = tM +

∆tG
2

Damit hängt die Lage des Segmentbogens von der tatsächlichen Rollenposition ab, während seine

Länge unmittelbar aus der gewünschten Nachführzeit und dem Reservewinkel folgt.

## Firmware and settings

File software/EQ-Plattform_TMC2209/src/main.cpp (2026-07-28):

#include <Arduino.h>
#include <Wire.h>
#include <U8g2lib.h>

#include <TMCStepper.h>
#include <SoftwareSerial.h>

// OLED: 128x64 I2C SSD1306 (U8g2 page buffer mode -> MUCH lower SRAM on UNO)
U8G2_SSD1306_128X64_NONAME_1_HW_I2C u8g2(U8G2_R0, U8X8_PIN_NONE);

// --- TMC2209 (UART configured, still STEP/DIR driven) ---
static constexpr float R_SENSE = 0.11f;      // common value on many SilentStepStick boards (verify on your module)
static constexpr uint8_t TMC_ADDR = 0;       // MS1/MS2 address (0..3), usually 0

// --- Pins ---
// 3-position direction switch (ON-OFF-ON):
// - Switch COMMON -> GND
// - North contact  -> D5 Schalter links
// - South contact  -> D4 Schalter rechts
// Middle position leaves both contacts open => OFF
const int PIN_DIR_N = 5;              // North contact (active LOW)
const int PIN_DIR_S = 4;              // South contact (active LOW)

const int PIN_STEP  = 2;
const int PIN_DIR   = 3;
const int PIN_EN    = 8;
const int PIN_POT   = A0;             // 10k Poti

// --- TMC2209 UART (UNO/Nano uses SoftwareSerial) ---
const int PIN_TMC_RX = 6;             // Arduino RX  <- TMC2209 UART pin
const int PIN_TMC_TX = 7;             // Arduino TX  -> TMC2209 UART pin (recommend 1k in series)

SoftwareSerial TMC_SERIAL(PIN_TMC_RX, PIN_TMC_TX); // RX, TX
TMC2209Stepper driver(&TMC_SERIAL, R_SENSE, TMC_ADDR);

#define DIR_LEFT_IS_FORWARD  true     // true = North, false = South

// --- Mechanik/Geometrie ---
const float STEPS_PER_REV = 200.0f;   // NEMA17
const float MICROSTEPS    = 32.0f;    // TMC2209 set via UART (driver.microsteps())
const float ROLLER_R_MM   = 10.0f;     // Ø20 mm -> r=10 mm. Adjust to your shaft diameter!
const float R_MM          = 552.068f; // Pivot->contact radius (mm). Adjust to your geometry! (distance center south bearing to center of arc)
constexpr float MOTOR_PULLEY_TEETH = 16.0f;
constexpr float SHAFT_PULLEY_TEETH = 66.0f;
constexpr float GEAR_RATIO = SHAFT_PULLEY_TEETH / MOTOR_PULLEY_TEETH;

// Sternzeit
const float SIDEREAL_SEC  = 86164.0f;

// Debug / bench test: multiply tracking speed to make motion visible.
// Set to 1000.0f for a quick functional test, then put back to 1.0f for real tracking.
const float SPEED_MULT = 1.0f;

// --- Runtime values ---
float BASE_USPS = 0.0f; // µSteps/s bei Poti-Mitte

// If the potentiometer is missing/floating, we fall back to a fixed trim (1.00 = 100%).
const float TRIM_FALLBACK = 1.00f;
static bool g_pot_ok = true;   // updated by readTrimFactor()

// Trim (±10%)
const float TRIM_MIN = 0.90f;
const float TRIM_MAX = 1.10f;

// Step-Timing
const unsigned int STEP_PULSE_US = 3;
unsigned long lastStepMicros     = 0;
unsigned long stepIntervalMicros = 1000000UL;

// Small shared buffer to avoid large stack frames in drawing code
static char g_buf2[12];

// Helpers
static inline float clampf(float x, float a, float b) {
  return (x < a) ? a : (x > b) ? b : x;
}

static float shaftRevPerHourFromMotorUsps(float motorUstepsPerSecond) {
  return (motorUstepsPerSecond * 3600.0f)
       / (STEPS_PER_REV * MICROSTEPS * GEAR_RATIO);
}

void applySpeedToInterval(float usps);
float readTrimFactor() {
  // 8x average of ADC (0..1023) + min/max to detect floating input
  uint32_t acc = 0;
  int mn = 1023;
  int mx = 0;
  for (int i = 0; i < 8; ++i) {
    int v = analogRead(PIN_POT);
    acc += (uint32_t)v;
    if (v < mn) mn = v;
    if (v > mx) mx = v;
  }
  float raw = acc / 8.0f; // 0..1023

  // If the pot is not connected, A0 often floats and readings jump around.
  // Detect this by looking at the spread across samples.
  const int FLOAT_SPREAD = 60; // counts; tune if needed
  if ((mx - mn) > FLOAT_SPREAD) {
    g_pot_ok = false;
    return TRIM_FALLBACK;
  }

  // Also treat extreme rails as "no usable trim" (wiring error / short)
  if (raw < 2.0f || raw > 1021.0f) {
    g_pot_ok = false;
    return TRIM_FALLBACK;
  }

  g_pot_ok = true;

  // Deadband around center to avoid jitter
  const int CENTER_ADC = 512;  // adjust (e.g. 505..520)
  const int DEADBAND   = 8;    // ±8 Counts ≈ ±0,8 %
  if (raw > (CENTER_ADC - DEADBAND) && raw < (CENTER_ADC + DEADBAND)) {
    raw = CENTER_ADC;
  }

  // 0..1023 -> TRIM_MIN..TRIM_MAX
  float t = raw / 1023.0f; // 0..1
  return TRIM_MIN + (TRIM_MAX - TRIM_MIN) * t;
}
// --- OLED helper ---
void updateOled(bool tracking, bool forward, float smoothedTrim, float targetUsps, bool potOk) {
  // User-facing speed is always the drive-shaft speed.
  float revPerHour = shaftRevPerHourFromMotorUsps(targetUsps);

  static unsigned long lastDraw = 0;
  unsigned long now = millis();
  if (now - lastDraw < 500) return; // update every 500 ms max
  lastDraw = now;

  u8g2.firstPage();
  do {
    u8g2.setFont(u8g2_font_6x10_tf);
    u8g2.setCursor(10, 10); u8g2.print(F("EQ Platform"));
    u8g2.setCursor(10, 25); u8g2.print(F("Tracking: ")); u8g2.print(tracking ? F("ON") : F("OFF"));

    u8g2.setCursor(10, 35);
    u8g2.print(F("Direction: "));
    u8g2.print(forward ? F("North") : F("South"));

    // Trim as percentage (rounded)
    int pct = (int)(smoothedTrim * 100.0f + 0.5f);
    u8g2.setCursor(10, 45);
    u8g2.print(F("Trim: "));
    u8g2.print(pct);
    u8g2.print('%');
    if (!potOk) {
      u8g2.print(F(" FIX"));
    }

    // rev/h (two decimals)
    u8g2.setCursor(10, 55);
    u8g2.print(F("rev/h: "));
    dtostrf(revPerHour, 5, 2, g_buf2);
    u8g2.print(g_buf2);
  } while (u8g2.nextPage());
}

struct DirState {
  bool tracking;
  bool forward; // true = North, false = South
};

DirState readDirState() {
  pinMode(PIN_DIR_N, INPUT_PULLUP);
  pinMode(PIN_DIR_S, INPUT_PULLUP);

  bool northSelected = (digitalRead(PIN_DIR_N) == LOW);
  bool southSelected = (digitalRead(PIN_DIR_S) == LOW);

  // Middle position: neither contact connected -> OFF
  if (!northSelected && !southSelected) {
    return {false, true};
  }

  // Safety: if both are active, treat as OFF
  if (northSelected && southSelected) {
    return {false, true};
  }

  bool forward = northSelected; // north => forward
  if (!DIR_LEFT_IS_FORWARD) {
    forward = !forward;
  }

  return {true, forward};
}

void setup() {
  Serial.begin(115200);
  delay(100);

  // --- TMC2209 UART init ---
  TMC_SERIAL.begin(115200);

  driver.begin();
  driver.pdn_disable(true);        // enable UART control
  driver.I_scale_analog(false);    // use internal current reference (ignore Vref pot)
  driver.toff(4);                  // enable driver
  driver.blank_time(24);
  driver.rms_current(600);         // mA RMS (tune for your motor)
  driver.microsteps((uint16_t)MICROSTEPS);
  driver.intpol(true);             // interpolate to 256
  driver.pwm_autoscale(true);      // stealthChop helper
  driver.en_spreadCycle(false);    // false=stealthChop (quiet), true=spreadCycle (torque)
  driver.TPOWERDOWN(10);

  BASE_USPS = (STEPS_PER_REV * MICROSTEPS / SIDEREAL_SEC)
            * (R_MM / ROLLER_R_MM)
            * GEAR_RATIO
            * SPEED_MULT;

  float uStepsPerHour = BASE_USPS * 3600.0f;
  float motorRevPerHour = uStepsPerHour / (STEPS_PER_REV * MICROSTEPS);
  float shaftRevPerHour = motorRevPerHour / GEAR_RATIO;
  float minutesPerRev = 60.0f / shaftRevPerHour;

  Serial.println(F("=== EQ Platform Driver ==="));
  Serial.print(F("R (mm): ")); Serial.println(R_MM, 3);
  Serial.print(F("Roller r (mm): ")); Serial.println(ROLLER_R_MM, 3);
  Serial.print(F("Steps/rev: ")); Serial.println(STEPS_PER_REV, 0);
  Serial.print(F("Microsteps: ")); Serial.println(MICROSTEPS, 0);
  Serial.print(F("Motor pulley teeth: ")); Serial.println(MOTOR_PULLEY_TEETH, 0);
  Serial.print(F("Shaft pulley teeth: ")); Serial.println(SHAFT_PULLEY_TEETH, 0);
  Serial.print(F("Gear ratio: ")); Serial.println(GEAR_RATIO, 3);
  Serial.print(F("Speed multiplier: ")); Serial.println(SPEED_MULT, 3);
  Serial.print(F("Driver: ")); Serial.println(F("TMC2209 (UART)"));
  Serial.print(F("RMS current (mA): ")); Serial.println(600);
  Serial.print(F("Motor base rate (uSteps/s): ")); Serial.println(BASE_USPS, 3);
  Serial.print(F("Motor revolutions per hour: ")); Serial.println(motorRevPerHour, 3);
  Serial.print(F("Shaft revolutions per hour: ")); Serial.println(shaftRevPerHour, 3);
  Serial.print(F("Shaft minutes per revolution: ")); Serial.println(minutesPerRev, 2);
  Serial.print(F("Trim range: ")); Serial.print(TRIM_MIN*100,0);
  Serial.print(F("% .. ")); Serial.print(TRIM_MAX*100,0); Serial.println(F("%"));

  pinMode(PIN_STEP, OUTPUT);
  pinMode(PIN_DIR,  OUTPUT);
  pinMode(PIN_EN,   OUTPUT);

  digitalWrite(PIN_EN, HIGH);                // driver disabled at startup

  DirState st0 = readDirState();
  digitalWrite(PIN_DIR, st0.forward ? HIGH : LOW);

  float usps = BASE_USPS * readTrimFactor();
  applySpeedToInterval(usps);
  lastStepMicros = micros();

  analogReference(DEFAULT);

  Serial.print(F("Start usps: ")); Serial.println(usps, 3);
  Serial.print(F("Step interval (ms): "));
  Serial.println(stepIntervalMicros / 1000.0f, 3);

  // I2C init
  Wire.begin();

  // --- OLED init (U8g2) ---
  u8g2.begin();
  u8g2.setI2CAddress(0x3C << 1);
  u8g2.firstPage();
  do {
    u8g2.setFont(u8g2_font_6x10_tf);
    u8g2.setCursor(0, 12); u8g2.print(F("EQ Platform"));
    u8g2.setCursor(0, 28); u8g2.print(F("Boot OK"));
  } while (u8g2.nextPage());
}

void loop() {
  DirState st = readDirState();
  bool tracking = st.tracking;
  unsigned long nowMs = millis();
  static bool lastTracking = false;
  static unsigned long lastTrackingChangeMs = 0;
  if (tracking != lastTracking && (nowMs - lastTrackingChangeMs) >= 2000) {
    if (tracking) {
      Serial.println(F("Tracking: ON"));
    } else {
      Serial.println(F("Tracking: OFF"));
    }
    lastTracking = tracking;
    lastTrackingChangeMs = nowMs;
  }
  // TMC2209 EN pin is typically active-low (same as A4988)
  digitalWrite(PIN_EN, tracking ? LOW : HIGH); // LOW = Driver active

  bool forward = st.forward;
  digitalWrite(PIN_DIR, forward ? HIGH : LOW);
  static bool lastForward = false;
  static unsigned long lastDirChangeMs = 0;
  static unsigned long dirChangedAt = 0;
  if (tracking && forward != lastForward && (nowMs - lastDirChangeMs) >= 2000) {
    if (forward) {
      Serial.println(F("Direction: North"));
    } else {
      Serial.println(F("Direction: South"));
    }
    lastForward = forward;
    lastDirChangeMs = nowMs;
    dirChangedAt = micros();
  }

  // Read potentiometer -> trim factor and resulting speed
  float trimFactor = readTrimFactor();

  // Exponential smoothing (EMA)
  static float smoothedTrim = -1.0f;
  if (smoothedTrim < 0.0f) smoothedTrim = trimFactor;  // Initialize on first run
  const float ALPHA = 0.2f;                             // 0..1, lower = smoother
  smoothedTrim = smoothedTrim + ALPHA * (trimFactor - smoothedTrim);

  float targetUsps = BASE_USPS * smoothedTrim;
  applySpeedToInterval(targetUsps);

  updateOled(tracking, forward, smoothedTrim, targetUsps, g_pot_ok);

  // Debug output: trim factor and effective speed every 2 seconds
  static unsigned long lastPrint = 0;
  if (millis() - lastPrint > 2000) {
    Serial.print(F("Trim=")); Serial.print(smoothedTrim, 3);
    Serial.print(F("  uSteps/s=")); Serial.println(targetUsps, 3);
    lastPrint = millis();
  }

  if (!tracking) return;

  // ensure at least 500 µs after a DIR change before a step occurs
  if ((long)(micros() - dirChangedAt) < 500) {
    return;
  }

  unsigned long now = micros();
  if ((long)(now - lastStepMicros) >= (long)stepIntervalMicros) {
    digitalWrite(PIN_STEP, HIGH);
    delayMicroseconds(STEP_PULSE_US);
    digitalWrite(PIN_STEP, LOW);

    lastStepMicros += stepIntervalMicros;
    if ((long)(now - lastStepMicros) >= (long)stepIntervalMicros) {
      lastStepMicros = now;
    }
  }
}

void applySpeedToInterval(float usps) {
  if (usps < 0.0001f) usps = 0.0001f;
  stepIntervalMicros = (unsigned long)(1000000.0f / usps);
}

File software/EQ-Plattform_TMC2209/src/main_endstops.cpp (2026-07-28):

#include <Arduino.h>
#include <avr/interrupt.h>
#include <util/atomic.h>

#include <Wire.h>
#include <U8g2lib.h>

#include <TMCStepper.h>
#include <SoftwareSerial.h>

// ================================
//  Hardware / Pins
// ================================

// 3-position direction switch (ON-OFF-ON):
// - COMMON -> GND
// - North contact -> D5
// - South contact -> D4
// Middle position leaves both contacts open.
static constexpr uint8_t PIN_DIR_N = 5;   // active LOW
static constexpr uint8_t PIN_DIR_S = 4;   // active LOW

static constexpr uint8_t PIN_STEP = 2;    // UNO D2 (PD2)
static constexpr uint8_t PIN_DIR  = 3;
static constexpr uint8_t PIN_EN   = 8;    // active LOW (TMC enable)
static constexpr uint8_t PIN_POT  = A0;

// Button + Endstops (NO switches wired to GND with INPUT_PULLUP)
static constexpr uint8_t PIN_HOME_BTN     = 9;
static constexpr uint8_t PIN_ENDSTOP_END  = 10;
static constexpr uint8_t PIN_ENDSTOP_HOME = 11;

// Endstop polarity:
//  - NO to GND + INPUT_PULLUP => pressed == LOW
static constexpr bool ENDSTOP_ACTIVE_LOW = true;

// ================================
//  TMC2209 (UART config, STEP/DIR motion)
// ================================
static constexpr float   R_SENSE  = 0.11f;
// UART slave address (0..3). Must match the driver CFG/MS pins.
static constexpr uint8_t TMC_ADDR = 0;

// 1-wire UART (factory default on BTT TMC2209 V1.3):
//   Arduino D6 (RX)  -> PDN_UART (Pin 4 on the module)
//   Arduino D7 (TX)  -> 1k -> PDN_UART (same pin)
// Note: RX and TX from the Arduino are tied together at PDN_UART externally.
static constexpr uint8_t PIN_TMC_RX = 6; // Arduino RX
static constexpr uint8_t PIN_TMC_TX = 7; // Arduino TX

// TMC2209 UART is 115200 8N1.
static constexpr uint32_t TMC_BAUD = 115200UL;

SoftwareSerial  TMC_SERIAL(PIN_TMC_RX, PIN_TMC_TX);
TMC2209Stepper  driver(&TMC_SERIAL, R_SENSE, TMC_ADDR);

// Motor current profiles (mA RMS). Higher current gives more torque, but also more heat.
static constexpr uint16_t MOTOR_CURRENT_TRACKING_MA    = 1100;
static constexpr uint16_t MOTOR_CURRENT_HOMING_FAST_MA = 1200;
static constexpr uint16_t MOTOR_CURRENT_HOMING_SLOW_MA = 1100;

// If your switch orientation is reversed, flip this.
static constexpr bool DIR_LEFT_IS_FORWARD = true; // true=North, false=South

// Reverse only the electrical motor direction while keeping North/South semantics intact.
static constexpr bool MOTOR_DIRECTION_INVERTED = true;

static uint8_t motorDirectionLevel(bool forward) {
  return (forward ^ MOTOR_DIRECTION_INVERTED) ? HIGH : LOW;
}

// ================================
//  Mechanics / Tracking
// ================================
static constexpr float STEPS_PER_REV = 200.0f;
static constexpr float MICROSTEPS    = 32.0f;
static constexpr float ROLLER_R_MM   = 10.0f;     // Ø20mm roller
static constexpr float R_MM          = 561.263f;  // platform geometry
constexpr float MOTOR_PULLEY_TEETH = 16.0f;
constexpr float SHAFT_PULLEY_TEETH = 66.0f;
// Motor revolutions per drive-shaft revolution.
constexpr float GEAR_RATIO = SHAFT_PULLEY_TEETH / MOTOR_PULLEY_TEETH;
static constexpr float SIDEREAL_SEC  = 86164.0f;
static constexpr float LUNAR_SEC     = 89428.0f;  // mean lunar day
static constexpr float LUNAR_RATE_FACTOR = SIDEREAL_SEC / LUNAR_SEC;

// Multiplier for bench tests (1.0 for real tracking)
static constexpr float SPEED_MULT    = 1.0f;

// Pot trim
static constexpr float TRIM_PLUS     = 1.20f;
static constexpr float TRIM_CENTER   = 1.00f;
static constexpr float TRIM_MINUS    = 0.80f;
static constexpr float TRIM_FALLBACK = 1.00f;
static constexpr int POT_ADC_PLUS    = 0;
static constexpr int POT_ADC_CENTER  = 512;
// Calibrated from the observed 94% at the physical minus end position.
static constexpr int POT_ADC_MINUS   = 665;
static bool g_pot_ok = true;

// ================================
//  OLED (U8X8 text-mode for smooth motion)
// ================================
U8X8_SSD1306_128X64_NONAME_HW_I2C u8x8(U8X8_PIN_NONE);
static char g_buf[16];

// ================================
//  Motion state
// ================================
enum MotionMode : uint8_t { MODE_IDLE = 0, MODE_TRACKING, MODE_HOMING };
enum HomingPhase : uint8_t { HOME_PHASE_IDLE = 0, HOME_PHASE_FAST_APPROACH, HOME_PHASE_BACKOFF, HOME_PHASE_SLOW_APPROACH };

static MotionMode  g_mode       = MODE_IDLE;
static HomingPhase g_home_phase = HOME_PHASE_IDLE;

// Last selected direction from the switch
static bool g_track_forward   = true;
static bool g_track_dir_valid = false;
static bool g_lunar_tracking  = false;

// Fallback home direction (only used before a valid track direction was ever read)
static constexpr bool HOME_DIR_FORWARD_FALLBACK = false; // false=South, true=North

// ================================
//  Homing config (tuning)
// ================================
// Direction selection:
//  - If you tracked North => home goes South (and vice versa)
static constexpr bool HOME_DIR_IS_OPPOSITE_OF_TRACK = true;

// Speeds are derived from BASE_USPS (sidereal) using multipliers.
static constexpr float HOME_FAST_MULT    = 350.0f;
static constexpr float HOME_BACKOFF_MULT = 160.0f;
static constexpr float HOME_SLOW_MULT    = 50.0f;

// Backoff distance expressed at the drive shaft, independent of the belt ratio.
static constexpr float HOME_BACKOFF_SHAFT_REVS = 0.25f;
static constexpr uint32_t HOME_BACKOFF_USTEPS =
  (uint32_t)(HOME_BACKOFF_SHAFT_REVS * STEPS_PER_REV * MICROSTEPS * GEAR_RATIO + 0.5f);
static constexpr unsigned long HOME_BACKOFF_MAX_MS = 2000UL;

// Grace period after starting homing during which END pressed is tolerated
static constexpr unsigned long HOMING_END_GRACE_MS = 300UL;

// ================================
//  Homing runtime state
// ================================
static bool g_home_dir_forward    = HOME_DIR_FORWARD_FALLBACK;
static bool g_homing_dir_flipped  = false;
static unsigned long g_homing_started_ms = 0;

static uint32_t g_backoff_remaining = 0;
static unsigned long g_backoff_started_ms = 0;

// Homing speeds (uSteps/s), computed in setup()
static float BASE_USPS = 800.0f;
static float HOMING_FAST_USPS    = 0.0f;
static float HOMING_BACKOFF_USPS = 0.0f;
static float HOMING_SLOW_USPS    = 0.0f;

// ================================
//  Timer1 step generator (TRACKING only)
// ================================
static constexpr uint16_t STEP_PULSE_US = 5;
static constexpr uint32_t T1_HZ = 2000000UL; // 2 MHz (prescaler 8)

// Shared ISR state
volatile uint32_t g_interval_ticks = 2000000UL;
volatile bool     g_step_run       = false;
volatile bool     g_step_blocked   = false;
volatile bool     g_step_high      = false;
volatile uint32_t g_pause_ticks    = 0; // 0.5us ticks
volatile uint32_t g_wait_ticks     = 0; // 0.5us ticks

static inline uint32_t usToTicks(uint32_t us) { return us * 2UL; }
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

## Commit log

2025-11-27 Revise README with project details and instructions
    Updated project name and added sections for features, repository contents, assembly instructions, and license.
2025-11-27 Update links for STEP and BOM files
2026-01-16 Add BOM
    [Teileliste_DM EQ Plattform.csv]
2026-01-17 link zu 20m linearwelle
    [Teileliste_DM EQ Plattform.csv]
2026-01-17 added M10 gewindeeinsatz
    [Teileliste_DM EQ Plattform.csv]
2026-01-17 path to BOM
2026-01-17 correct path to BOM
2026-01-17 corrected BOM path
2026-01-17 PCB and software optinal
2026-01-17 PCB EQ2 motor
2026-01-24 Add TMC2209 driver initialization and configuration to main.cpp
2026-01-24 Add breadboard test sketch for TMC2209 driver
2026-01-24 Refactor direction handling and update pin definitions for TMC2209
2026-01-24 Implement 3-position direction switch for motor control in test sketch
2026-01-24 Add alternate upload speed configuration for Arduino UNO and update upload speed for CH340 clones
2026-01-25 Update roller radius to 10mm for accurate shaft diameter adjustment
2026-01-25 Fix formatting issues and update links in BOM for improved clarity and accuracy
    [Teileliste_DM EQ Plattform.csv]
2026-01-26 Fix pin assignments for direction switch in main.cpp
    [main.cpp]
2026-01-26 Refactor code structure for improved readability and maintainability
    [Gehäuse_tmc2209.stl, case.stl, case_EQ-Plattform.3mf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]
2026-01-30 feat: add main endstops functionality with TMC2209 integration
2026-01-30 Add .DS_Store file to hardware/mechanical directory
    [Kreissegment 50Grad_neu.step, Unterplatte.step]
2026-01-30 feat: enhance homing safety with automatic direction flip on endstop hit
    [main_endstops.cpp]
2026-01-30 feat: implement timer-driven step timing and enhance homing functionality
2026-01-31 feat: enhance step timing and endstop handling with optimized ISR and new step motor slice function
2026-01-31 feat: enhance endstop handling with improved polarity detection and homing safety
2026-01-31 fix: adjust OLED display cursor positions for better layout
    [main_endstops.cpp]
2026-02-14 update motor movement
2026-02-15 chore: update binary files in circuitboard directory
    [EQ-Plattform_PCB Case.3mf]
2026-02-15 refactor: improve TMC2209 configuration and update UART settings
2026-02-15 fix: correct trim values and adjust home speed multipliers for improved performance
    [main_endstops.cpp]
2026-02-24 chore: update PCB case design file
    [EQ-Plattform_PCB Case.3mf]
2026-06-16 docs: update index.md for improved descriptions and added assembly details
2026-06-16 docs: enhance index.md with detailed assembly steps and component list
2026-07-28 Refactor motor control logic and update gearing parameters
    - Updated the description of GT2 belt components in the documentation.
    - Introduced constants for motor and shaft pulley teeth and calculated gear ratio in main control files.
    - Adjusted calculations for revolutions per hour and minutes per revolution to account for gear ratio.
    - Enhanced OLED display output to include motor and shaft revolutions per hour and gear ratio.
    - Added driver profiles for motor current management during tracking and homing phases.
    - Implemented lunar tracking mode with adjusted speed calculations based on lunar rate factor.
    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
    [Kreissegment 50Grad_neu.step, Oberplatte.step, Oberplatte_simple.step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]
2026-07-29 browswe flasher added
    [Teileliste_DM EQ Plattform.csv]
2026-07-29 Update pulley selection (#12)
    [Teileliste_DM EQ Plattform.csv]
2026-07-29 Consolidate motor parts list (#13)
    [Teileliste_DM EQ Plattform.csv]
2026-07-29 Update parts list CSV with new entries and links
    [Teileliste_DM EQ Plattform.csv]
2026-08-05 suedlager 40°-60° added
    [Kugelgelenkhalter.step, Suedlager Erhoehung 18mm fuer 50° Winkel.step, Suedlager_40°.step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]
2026-08-05 Rename heading from 'Aluminiumsegmente' to 'Segmente und Südlager'
2026-08-18 Add ESP32 support with web app and update documentation
    - Introduced main_esp32.cpp for ESP32 DevKit V1 with pin assignments and functionality.
    - Updated platformio.ini to include ESP32 environment for firmware compilation.
    - Enhanced README.md to include ESP32 features, installation instructions, and web app details.
    - Expanded software/README.md with ESP32 configuration and usage instructions.
2026-08-18 Add firmware release documentation and SHA256 checksums
    - Created README.md in the release directory detailing the firmware files for Arduino Uno/Nano and ESP32.
    - Added SHA256SUMS.txt to provide checksum verification for the firmware files.
